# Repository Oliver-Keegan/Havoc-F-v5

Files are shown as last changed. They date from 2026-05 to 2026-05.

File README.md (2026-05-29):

# Havoc-F-v5
This is the latest version of my flipper battlebot: Havoc F. I designed it in Onshape and 3D printed the chassis in two materials, TPU and PETG-CF on my Bambu Lab P1S. The previous version can be found on Thingiverse: https://www.thingiverse.com/Oliver_Keegan/designs

The most important change is the scoop. It uses a sheet metal formed steel scoop that I had manufactured and hard coat anodized at JLCCNC. The quality and price of this was impressive and it makes the robot significantly more effective and durable. I got it manufactured here: https://jlccnc.com/?from=Oliver1

_____________________________________________________________________________

Here's the parts list:

4x Wheel Any rigid filament

1x Main Body - Any rigid filament

1x Top Plate - Any rigid filament, but for improved durability, use TPU

1x Lifter Arm - Any rigid filament

1x Lifter Joint

1x Scoop (I highly recommend getting it manufactured by a company like JLCCNC, its great value and the quality of the part I got was very impressive)

12x M2*6 screws

2x M2*12 screws

6x M2*4 screws

1x M1.4*6 screw

1x M2*25 screw

16x M2 brass heated inserts (significantly improves durability)

4x N10 or N20 brushed motors (RPM is up to you, use N10s to be more safely below 150g) https://shop.bristolbotbuilders.com/product/n10/

1x Malenki Nano https://shop.bristolbotbuilders.com/product/malenki/

1x 2S HV High Speed Metal Geared Servo https://shop.bristolbotbuilders.com/product/hsservo/

1x Aluminium servo horn https://shop.bristolbotbuilders.com/product/horn/

1x 2S LiPo battery (I recommend airsoft batteries as they are really compact)

1x SPDT Slide Switch

4x 16mm diameter O-rings

_____________________________________________________________________________

RECOMMENDED PRINT SETTINGS:

For all PETG-CF or rigid parts:

0.15mm layer height

20% gyroid infill

2 walls

2 top shell layers

5 bottom shell layers

For TPU or flexible parts:

0.28mm layer height

0% infill (makes it cushiony)

2 walls

5 top and bottom shell layers

_____________________________________________________________________________

Assembly:

1) Solder your electronics, using battery connectors if necessary, I just directly soldered the battery leads to a switch (leave unconnected to the switch until you put the top plate on) and the Malenki. Measure your wire lengths to be efficient with space. For the motors, solder both right side motors to the same pads, and the same with left side motors.

2) Slide the motors into their slots in the frame. be careful to put the right motors in the right places.

3) Screw the servo horn onto the servo, power it on first to make sure its at the 0° position.

4) Slide the servo into place, ensuring that the side with the wires protruding is closes to the rear of the robot.

5) Melt 12 brass heated inserts into the frame in every hole, use a soldering iron at around 220°C.

6) Put the O-rings onto the wheels and fit them onto the motor shafts, they have a slot so be careful to orient them correctly.

7) Use 7 M26 screws to secure the TPU armour onto the robot.

8) Press the heated inserts into the 4 holes on the lifting arm.

9) Use the M1.46 screw to connect the lifter joint to the 3rd hole from the end of the servo horn, the horn should be inside the gap of the lifter joint.

10) Connect the lifter joint to the lifting arm by screwing the M225 screw all the way through, with the lifting joint in the gap in the middle of the arm.

11) Screw the lifting arm onto the top plate using the two M212 screws, running them through the two bumps with holes on the top plate.

12) Solder the switch onto your power line, with the switch on the outside of the robot with screws holding it down from above, or on the inside with screws holding it from 13) below.

14) Screw on the top plate with 5 M26 screws, make sure the rectangular blocks underneath it slot into the motor slots for proper alignment.

15) Attach your scoop with the four M24 screws.

16) Bind your Malenki to your FLYSKY transmitter by pressing the bind button when you turn on the transmitter, and then switching the robot on and off quickly three times.

Done!

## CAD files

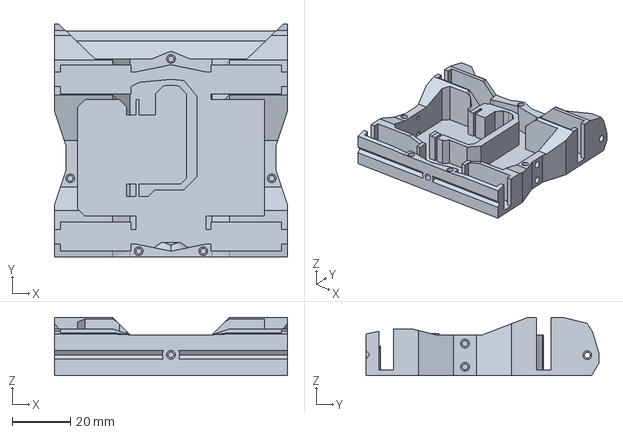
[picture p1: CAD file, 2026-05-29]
STEP/Havoc F v5 Long - Main Body.step
80.0 x 80.0 x 20.0 mm

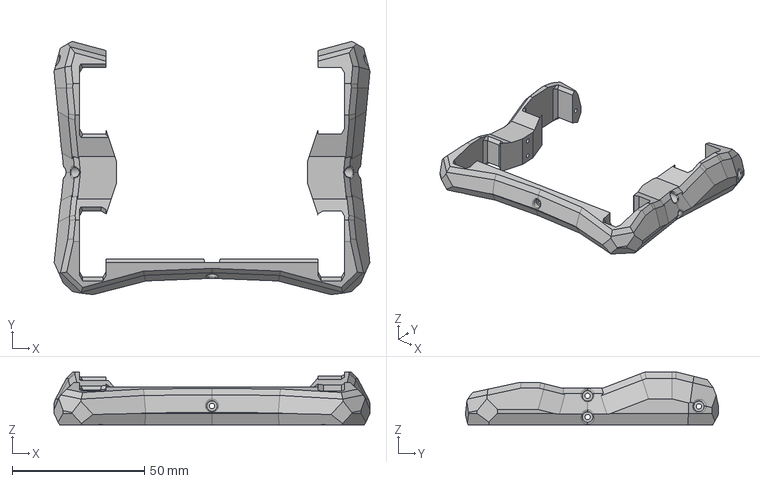
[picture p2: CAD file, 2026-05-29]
STEP/Havoc F v5 Long - TPU Armour.step
119.3 x 95.6 x 20.0 mm

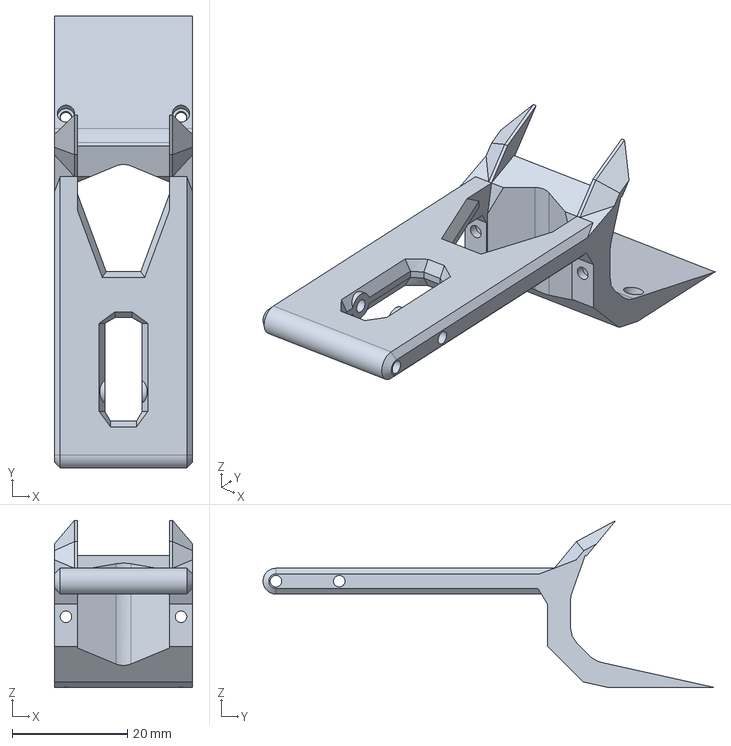
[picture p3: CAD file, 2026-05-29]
STEP/Havoc F v5 Long - Lifter Arm.step
24.0 x 78.6 x 29.1 mm

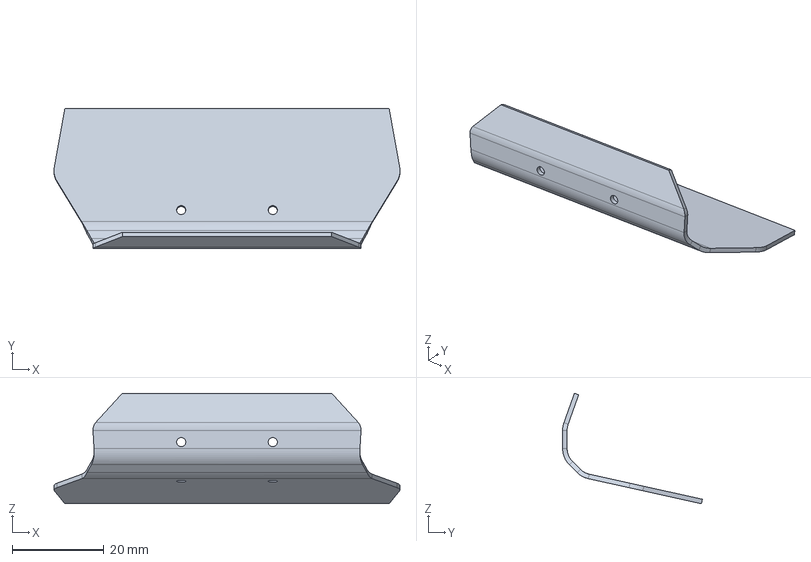
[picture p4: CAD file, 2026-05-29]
STEP/Havoc F v5 Long - Scoop.step
75.6 x 30.5 x 24.1 mm

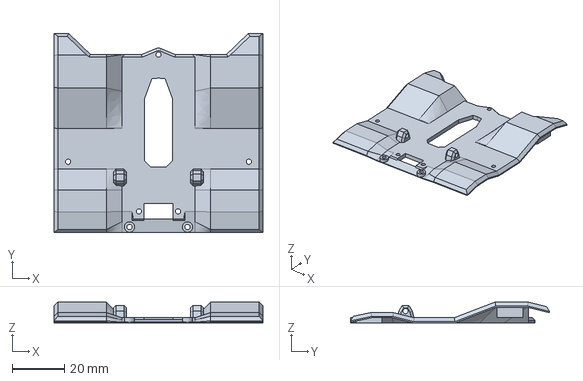
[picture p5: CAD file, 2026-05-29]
STEP/Havoc F v5 Long - Top Plate.step
80.0 x 76.2 x 8.00 mm

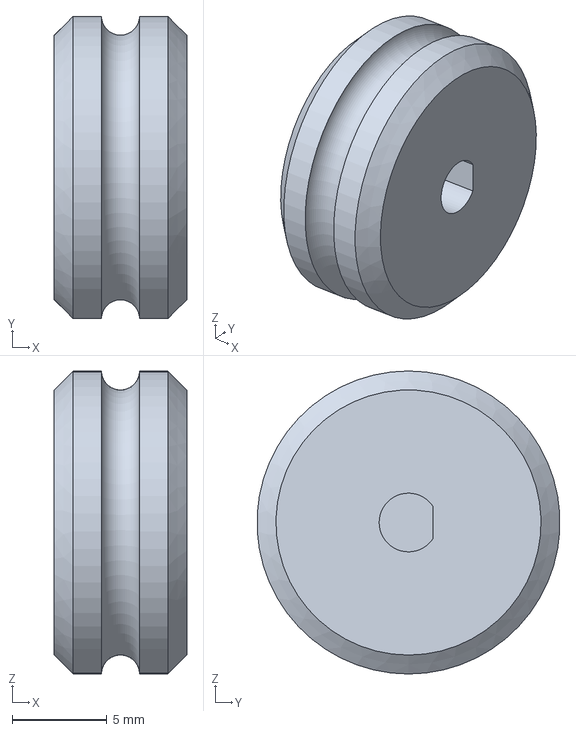
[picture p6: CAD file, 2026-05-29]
STEP/Havoc F v5 Long - Wheel.step
7.00 x 16.0 x 16.0 mm

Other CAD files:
STL/Havoc F v5 Long - Lifter Arm.stl
STL/Havoc F v5 Long - Main Body.stl
STL/Havoc F v5 Long - Scoop.stl
STL/Havoc F v5 Long - TPU Armour.stl
STL/Havoc F v5 Long - Top Plate.stl
STL/Havoc F v5 Long - Wheel.stl

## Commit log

2026-05-29 Update Havoc F v5 Long - Top Plate.step
    [Havoc F v5 Long - Part 5 (3).step]
2026-05-29 Rename Havoc F v5 Long - Top Plate.step
    [Havoc F v5 Long - Top Plate.step]
2026-05-29 Create STL Files
2026-05-29 Rename STL Files to STL/Havoc F v5
